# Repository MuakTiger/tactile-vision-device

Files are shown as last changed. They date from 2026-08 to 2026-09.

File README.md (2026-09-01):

# Tactile Vision Device
> Real-time visual-to-tactile substitution device for the visually impaired.  
> 카메라의 깊이 정보를 24개의 촉각 핀으로 변환해 공간을 손끝에 전달합니다.

---

## Hardware Preview

<a href="hardware/full/7_22 set_final.stl">
  
</a>

> Click the badge above, or click the STL file directly on GitHub to launch the interactive 3D viewer.

**[→ Open Full Assembly STL (interactive 3D viewer)](hardware/full/7_22%20set_final.stl)**

| Part | STL |
|---|---|
| Full Assembly (24-zone tactile display) | [7_22 set_final.stl](hardware/full/7_22%20set_final.stl) |
| Servo + Rack & Pinion unit | [SG90 and Rack and Pinion.stl](hardware/assembly/SG90%20and%20Rack%20and%20Pinion.stl) |
| Rack | [rack.stl](hardware/parts/rack.stl) |
| Pinion | [pinion.stl](hardware/parts/pinion.stl) |
| Servo bracket | [servo_bracket.stl](hardware/parts/servo_bracket.stl) |

---

## Project Structure

```
tactile-vision-device/
├── software/
│   ├── main.py              # Jetson main pipeline
│   ├── requirements.txt
│   └── pico/
│       └── main.cpp         # Raspberry Pi Pico firmware
└── hardware/
    ├── parts/               # rack.stl / pinion.stl / servo_bracket.stl
    ├── assembly/            # SG90 + rack & pinion unit
    └── full/                # complete 24-zone tactile display
```

---

## System Overview

```
Camera
  │
  ▼
Jetson Orin Developer Kit
  ├─ Depth Anything V2 (TensorRT)
  ├─ 6×4 grid depth mapping (24 zones)
  └─ UART  "GRID:v0,...,v23\n"
          │
          ▼
Raspberry Pi Pico
  ├─ I2C → PCA9685 #1 (0x40) → SG90 ×12  [rows 1–2]
  └─ I2C → PCA9685 #2 (0x41) → SG90 ×12  [rows 3–4]
                  │
                  ▼
        Rack & Pinion — Z-axis pin extrusion
```

## Grid Layout

```
[ 0][ 1][ 2][ 3][ 4][ 5]   row 1 ┐ PCA9685 0x40
[ 6][ 7][ 8][ 9][10][11]   row 2 ┘
[12][13][14][15][16][17]   row 3 ┐ PCA9685 0x41
[18][19][20][21][22][23]   row 4 ┘
```

Higher depth value = closer object = pin extends further.

---

## Hardware

| Component | Spec |
|---|---|
| Main board | NVIDIA Jetson Orin Developer Kit |
| MCU | Raspberry Pi Pico (RP2040) |
| PWM driver | PCA9685 × 2 (I2C: `0x40`, `0x41`) |
| Actuator | SG90 servo × 24 |
| Mechanism | Rack & pinion, Z-axis extrusion (3D printed) |
| Camera | USB webcam (MJPEG, 720p) |

---

## Getting Started

### Jetson

```bash
pip install -r software/requirements.txt
# Place TRT engine → checkpoints/depth_anything_v2_vits.engine

python software/main.py              # run
python software/main.py --debug      # with visualization
python software/main.py --no-hw      # software only
```

| Option | Default | Description |
|---|---|---|
| `--port` | `/dev/ttyACM0` | Pico serial port |
| `--baud` | `115200` | Baud rate |
| `--debug` | `False` | Show depth grid overlay |
| `--no-hw` | `False` | Run without hardware |

### Pico Firmware

1. Install [Arduino IDE](https://www.arduino.cc/en/software)
2. Add board URL in **Preferences**:
   ```
   https://github.com/earlephilhower/arduino-pico/releases/download/global/package_rp2040_index.json
   ```
3. Install **Raspberry Pi Pico/RP2040** via Board Manager
4. Install **Adafruit PWM Servo Driver Library**
5. Upload `software/pico/main.cpp`

**I2C wiring:** `GP4` → SDA, `GP5` → SCL

**Before first run** — lower `SAFE_MAX` in `pico/main.cpp` to avoid mechanical damage:
```cpp
static constexpr uint16_t SAFE_MAX = 350;  // increase gradually after testing
```

---

## References

- [Depth Anything V2](https://github.com/DepthAnything/Depth-Anything-V2)
- [Ultralytics YOLO](https://github.com/ultralytics/ultralytics)
- [Adafruit PWM Servo Driver](https://github.com/adafruit/Adafruit-PWM-Servo-Driver-Library)
- [arduino-pico](https://github.com/earlephilhower/arduino-pico)

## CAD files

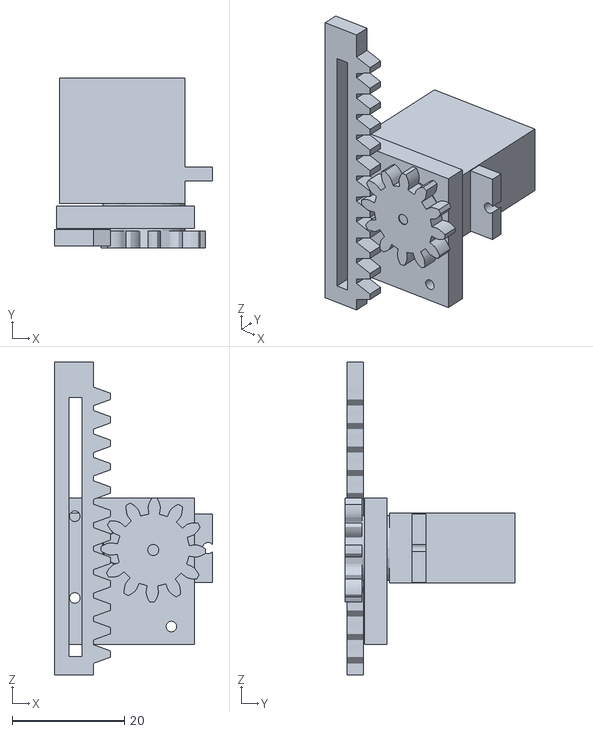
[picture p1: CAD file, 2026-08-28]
hardware/assembly/SG90 and Rack and Pinion.stl
28.2 x 30.4 x 55.9

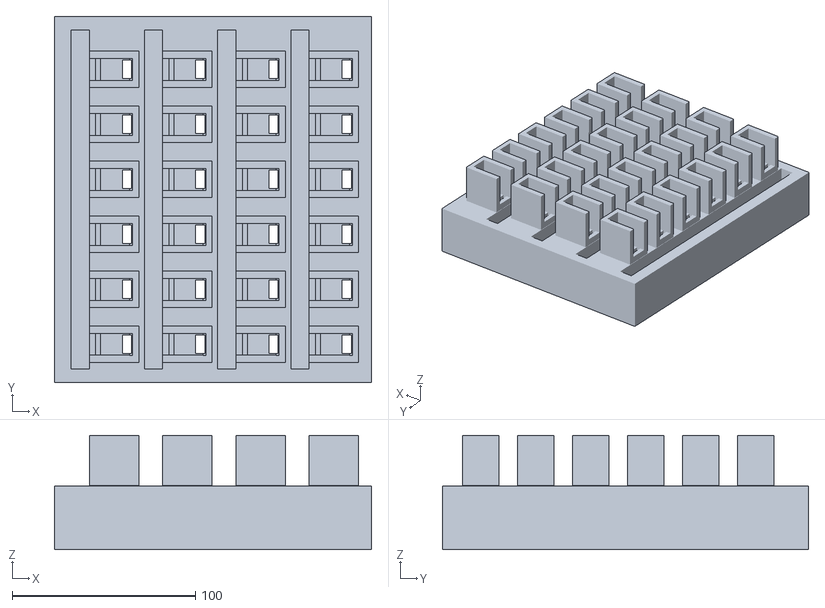
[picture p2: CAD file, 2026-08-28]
hardware/full/7_22 set_final.stl
173.0 x 200.0 x 62.3

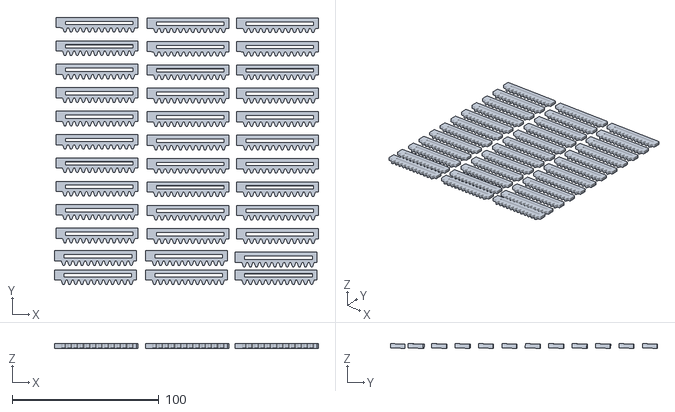
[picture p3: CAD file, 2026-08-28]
hardware/parts/rack.stl
179.9 x 182.1 x 3.17

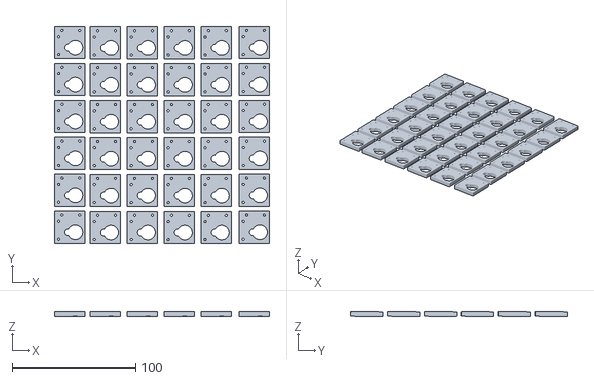
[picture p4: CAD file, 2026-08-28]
hardware/parts/servo_bracket.stl
174.7 x 176.5 x 4.46

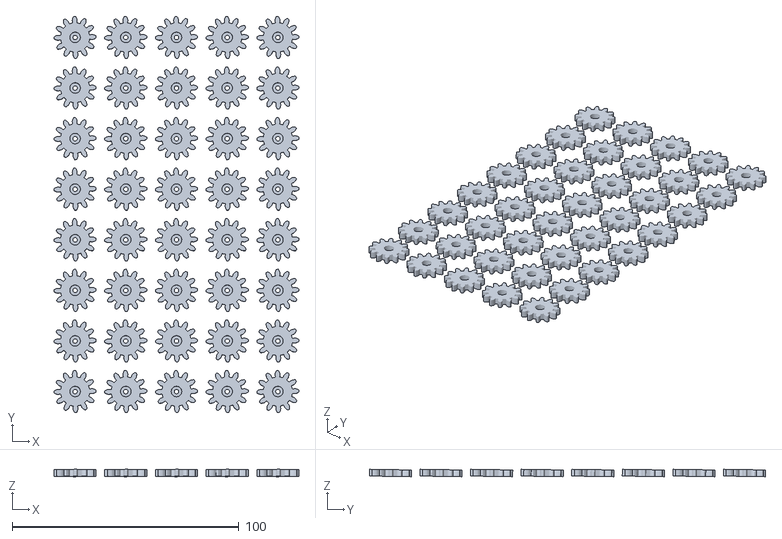
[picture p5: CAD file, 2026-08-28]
hardware/parts/pinion.stl
108.1 x 175.0 x 3.32

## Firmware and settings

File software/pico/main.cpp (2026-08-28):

/**
 * 시각-촉각 대체 보조장치 — Raspberry Pi Pico 펌웨어
 *
 * 구성:
 *   Jetson → USB UART → Pico → I2C → PCA9685 x2 → SG90 x24
 *   PCA9685 #1 (0x40): 채널 0~11 → 그리드 상단 12구역
 *   PCA9685 #2 (0x41): 채널 0~11 → 그리드 하단 12구역
 *
 * 수신 포맷: "GRID:v0,v1,...,v23\n"  (ASCII, 115200bps)
 *
 * 의존 라이브러리 (platformio.ini 또는 Arduino IDE):
 *   - Wire (내장)
 *   - adafruit/Adafruit PWM Servo Driver Library
 *
 * 하드웨어 연결:
 *   GP4 (SDA) → PCA9685 SDA
 *   GP5 (SCL) → PCA9685 SCL
 *   3V3 / GND → PCA9685 VCC / GND
 *   외부 5V   → PCA9685 V+ (서보 전원)
 */

#include <Arduino.h>
#include <Wire.h>
#include <Adafruit_PWMServoDriver.h>

// ──────────────────────────────────────────────
// 설정 상수
// ──────────────────────────────────────────────
static constexpr int    MOTOR_COUNT    = 24;
static constexpr int    BOARD_CH       = 12;   // 보드당 채널 수 (24 / 2)

// SG90 안전 PWM 범위 (50 Hz 기준, 4096 tick 단위)
// 랙앤피니언 실제 스트로크에 맞게 SAFE_MAX 조정 권장
// 처음 테스트 시: SAFE_MAX = 350 으로 낮게 시작
static constexpr uint16_t SAFE_MIN     = 250;  // ~0.5 ms → 핀 하강 (홈)
static constexpr uint16_t SAFE_MAX     = 490;  // ~2.3 ms → 핀 최대 상승

// 깊이값 하한 임계치 — 이 값 미만은 '물체 없음' → 홈 유지
static constexpr uint8_t  DEPTH_THR    = 20;

// 통신 Failsafe: 이 시간(ms) 동안 패킷 없으면 전체 홈 복귀
static constexpr unsigned long COMM_TIMEOUT = 2000;

// ──────────────────────────────────────────────
// PCA9685 객체
// ──────────────────────────────────────────────
Adafruit_PWMServoDriver pwm1 = Adafruit_PWMServoDriver(0x40); // 기본 보드
Adafruit_PWMServoDriver pwm2 = Adafruit_PWMServoDriver(0x41); // A0 납땜 보드

unsigned long lastReceiveTime = 0;

// ──────────────────────────────────────────────
// 전체 서보 홈 복귀
// ──────────────────────────────────────────────
void resetAllServos() {
  for (int i = 0; i < BOARD_CH; i++) {
    pwm1.setPWM(i, 0, SAFE_MIN);
    pwm2.setPWM(i, 0, SAFE_MIN);
  }
}

// ──────────────────────────────────────────────
// 깊이값(0~255) → PWM tick 변환
// Depth Anything V2: 값이 클수록 가까움 (disparity)
// → 가까울수록 막대가 더 올라옴 (SAFE_MAX 방향)
// ──────────────────────────────────────────────
uint16_t depthToPWM(uint8_t rawVal) {
  if (rawVal < DEPTH_THR) return SAFE_MIN;  // 물체 없음 → 홈
  return (uint16_t)map(rawVal, DEPTH_THR, 255, SAFE_MIN, SAFE_MAX);
}

// ──────────────────────────────────────────────
// 패킷 파싱: "GRID:v0,v1,...,v23"
// 반환값: 24개 파싱 성공 시 true
// ──────────────────────────────────────────────
bool parsePacket(const String& packet, uint8_t values[MOTOR_COUNT]) {
  if (!packet.startsWith("GRID:")) return false;

  String data = packet.substring(5);
  data.trim();

  char buf[128];
  data.toCharArray(buf, sizeof(buf));

  int    index = 0;
  char*  token = strtok(buf, ",");

  while (token != nullptr && index < MOTOR_COUNT) {
    int v       = atoi(token);
    values[index++] = (uint8_t)constrain(v, 0, 255);
    token = strtok(nullptr, ",");
  }

  return (index == MOTOR_COUNT);
}

// ──────────────────────────────────────────────
// 24개 서보 일괄 업데이트
// 가로 6 × 세로 4 그리드 (행 우선)
// index  0~11 → pwm1 (PCA9685 0x40) 채널 0~11  ← 상단 2행
// index 12~23 → pwm2 (PCA9685 0x41) 채널 0~11  ← 하단 2행
// ──────────────────────────────────────────────
void applyServos(uint8_t values[MOTOR_COUNT]) {
  for (int i = 0; i < BOARD_CH; i++) {
    pwm1.setPWM(i, 0, depthToPWM(values[i]));
    pwm2.setPWM(i, 0, depthToPWM(values[i + BOARD_CH]));
  }
}

// ──────────────────────────────────────────────
// 초기화
// ──────────────────────────────────────────────
void setup() {
  Wire.begin();               // GP4=SDA, GP5=SCL (arduino-pico 기본값)
  Serial.begin(115200);
  Serial.setTimeout(100);

  pwm1.begin();
  pwm1.setPWMFreq(50);        // SG90 표준 주파수 50 Hz

  pwm2.begin();
  pwm2.setPWMFreq(50);

  resetAllServos();           // 부팅 시 전체 홈 복귀
  delay(500);

  Serial.println("PICO_READY");
  lastReceiveTime = millis();
}

// ──────────────────────────────────────────────
// 메인 루프
// ──────────────────────────────────────────────
void loop() {
  // ── A. 패킷 수신 및 처리 ──
  if (Serial.available() > 0) {
    String packet = Serial.readStringUntil('\n');
    packet.trim();

    uint8_t values[MOTOR_COUNT];
    if (parsePacket(packet, values)) {
      applyServos(values);
      lastReceiveTime = millis();
    }
    // 파싱 실패 시 이전 포지션 유지 (갑작스러운 움직임 방지)
  }

  // ── B. Failsafe: 통신 단절 시 홈 복귀 ──
  if (millis() - lastReceiveTime > COMM_TIMEOUT) {
    resetAllServos();
    lastReceiveTime = millis();  // 반복 호출 방지
  }
}

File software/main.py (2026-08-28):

"""
시각장애인을 위한 실시간 시각-촉각 대체 보조장치
Jetson Orin Developer Kit 구동용 메인 파이프라인

파이프라인:
  웹캠 → Depth Anything V2 (TensorRT) → 4×6 그리드(가로6×세로4) → 시리얼 → Pico → PCA9685×2 → SG90×24

실행 예시:
  python main.py --debug                         # 시각화 창 포함 실행
  python main.py --no-hw                         # 하드웨어 없이 시각화만
  python main.py --port /dev/ttyACM1 --debug     # 시리얼 포트 지정
"""

import argparse
import logging
import time

import cv2
import numpy as np
import serial
import torch
import tensorrt as trt

# ──────────────────────────────────────────────────────────────────
# 로깅 설정
# ──────────────────────────────────────────────────────────────────
logging.basicConfig(
    level=logging.INFO,
    format="%(asctime)s [%(levelname)s] %(message)s",
)
logger = logging.getLogger(__name__)


# ──────────────────────────────────────────────────────────────────
# Depth Anything V2 – TensorRT 추론 클래스
# ──────────────────────────────────────────────────────────────────
class DepthEstimatorTRT:
    """
    Depth Anything V2 ViT-S TensorRT 엔진 래퍼.
    입력: BGR 518×518 ndarray
    출력: uint8 깊이맵 (0~255, 값이 클수록 가까움 – disparity 기반)
    """

    # ImageNet 정규화 상수
    MEAN = np.array([0.485, 0.456, 0.406], dtype=np.float32).reshape(3, 1, 1)
    STD  = np.array([0.229, 0.224, 0.225], dtype=np.float32).reshape(3, 1, 1)

    def __init__(self, engine_path: str, input_shape: tuple = (518, 518)):
        self.input_shape = input_shape

        trt_logger = trt.Logger(trt.Logger.WARNING)
        trt.init_libnvinfer_plugins(trt_logger, "")

        with open(engine_path, "rb") as f, trt.Runtime(trt_logger) as runtime:
            self.engine = runtime.deserialize_cuda_engine(f.read())

        self.context = self.engine.create_execution_context()
        self.stream  = torch.cuda.Stream()

        # 추론 버퍼 사전 할당 (매 프레임 메모리 재할당 방지)
        self.d_input  = torch.empty((1, 3, *input_shape), dtype=torch.float32, device="cuda")
        self.d_output = torch.empty((1, *input_shape),    dtype=torch.float32, device="cuda")
        self.context.set_tensor_address("input",  int(self.d_input.data_ptr()))
        self.context.set_tensor_address("output", int(self.d_output.data_ptr()))

        logger.info("DepthEstimator TRT 로드 완료: %s", engine_path)

    def infer(self, frame_518: np.ndarray) -> np.ndarray:
        """BGR 518×518 → 정규화 깊이맵 (uint8)"""
        # BGR → RGB → float32 정규화
        img = cv2.cvtColor(frame_518, cv2.COLOR_BGR2RGB).astype(np.float32) / 255.0
        img = (img.transpose(2, 0, 1) - self.MEAN) / self.STD  # (3, H, W)

        with torch.cuda.stream(self.stream):
            self.d_input.copy_(
                torch.from_numpy(np.ascontiguousarray(img[None])), non_blocking=True
            )
            self.context.execute_async_v3(stream_handle=self.stream.cuda_stream)
            self.stream.synchronize()

        depth_raw  = self.d_output.cpu().numpy()[0]
        depth_norm = cv2.normalize(depth_raw, None, 0, 255, cv2.NORM_MINMAX, dtype=cv2.CV_8U)
        return depth_norm


# ──────────────────────────────────────────────────────────────────
# 시리얼 통신 클래스 (젯슨 → 피코)
# ──────────────────────────────────────────────────────────────────
class HardwareCommunicator:
    """
    Raspberry Pi Pico와의 UART 시리얼 통신.
    전송 포맷: "GRID:v0,v1,...,v23\\n"  (ASCII 문자열)
    """

    def __init__(self, port: str, baudrate: int = 115200):
        self.conn = None
        try:
            self.conn = serial.Serial(port, baudrate, timeout=1.0)
            time.sleep(2.0)  # 피코 부팅 대기

            # 피코 준비 신호 수신 확인
            resp = self.conn.readline().decode("utf-8", errors="ignore").strip()
            if resp == "PICO_READY":
                logger.info("피코 연결 확인 (%s)", port)
            else:
                logger.warning("피코 응답 불명확: '%s' — 계속 진행합니다.", resp)

        except serial.SerialException as e:
            logger.warning("시리얼 연결 실패 (%s): %s → 오프라인 모드", port, e)

    @property
    def connected(self) -> bool:
        return self.conn is not None and self.conn.is_open

    def transmit(self, grid_values: list) -> bool:
        """24개 그리드 값을 피코로 전송. 성공 시 True 반환."""
        if not self.connected:
            return False
        packet = "GRID:" + ",".join(map(str, grid_values)) + "\n"
        try:
            self.conn.write(packet.encode("utf-8"))
            return True
        except serial.SerialException as e:
            logger.error("전송 실패: %s", e)
            return False

    def close(self):
        if self.connected:
            self.conn.close()
            logger.info("시리얼 포트 닫힘")


# ──────────────────────────────────────────────────────────────────
# 6×4 그리드 깊이 산출
# ──────────────────────────────────────────────────────────────────
def compute_grid(depth_norm: np.ndarray,
                 grid_h: int = 4,
                 grid_w: int = 6) -> list:
    """
    깊이맵 → 24개 구역 평균값 리스트 (행 우선, 좌→우, 위→아래)
    가로 6구역 × 세로 4구역 (사람 눈/모니터 비율 기준)

    인덱스 배치:
      [ 0  1  2  3  4  5]  ← 1행
      [ 6  7  8  9 10 11]  ← 2행  → PCA9685 0x40 (채널 0~11)
      [12 13 14 15 16 17]  ← 3행
      [18 19 20 21 22 23]  ← 4행  → PCA9685 0x41 (채널 0~11)
    """
    result = []
    for row_strip in np.array_split(depth_norm, grid_h, axis=0):
        for cell in np.array_split(row_strip, grid_w, axis=1):
            result.append(int(np.mean(cell)))
    return result  # len == 24


# ──────────────────────────────────────────────────────────────────
# 디버그 시각화
# ──────────────────────────────────────────────────────────────────
def draw_debug(depth_norm: np.ndarray,
               grid_values: list,
               fps: float,
               grid_h: int = 4,
               grid_w: int = 6) -> np.ndarray:
    """깊이맵에 그리드 오버레이 + FPS 표시"""
    vis = cv2.applyColorMap(depth_norm, cv2.COLORMAP_INFERNO)
    h, w = vis.shape[:2]
    rh, rw = h // grid_h, w // grid_w

    for r in range(grid_h):
        for c in range(grid_w):
            idx  = r * grid_w + c
            x1, y1 = c * rw, r * rh
            # 두 보드 경계(인덱스 12, 3행 시작) 강조
            border = (0, 255, 255) if idx == 12 else (180, 180, 180)
            cv2.rectangle(vis, (x1, y1), (x1 + rw, y1 + rh), border, 1)
            cv2.putText(
                vis, str(grid_values[idx]),
                (x1 + 4, y1 + 18),
                cv2.FONT_HERSHEY_SIMPLEX, 0.42,
                (255, 255, 255), 1, cv2.LINE_AA,
            )

    cv2.putText(
        vis, f"FPS: {fps:.1f}",
        (6, h - 8), cv2.FONT_HERSHEY_SIMPLEX,
        0.65, (0, 255, 0), 2, cv2.LINE_AA,
    )
    return vis
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

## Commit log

2026-08-28 feat: 시각-촉각 대체 보조장치 초기 구현
    - main.py: Depth Anything V2 TRT 추론 + 6×4 그리드 + 시리얼 전송
    - pico/main.cpp: PCA9685×2 I2C 제어, strtok 파싱, Failsafe
    - requirements.txt, README.md, .gitignore 추가
    [main.cpp, main.py]
2026-08-28 Update actuator description in README.md
2026-08-28 fix: 그리드 방향 수정 및 하드웨어 표기 정확화
    - 그리드 방향: 세로6×가로4 → 가로6×세로4 (GRID_H=4, GRID_W=6)
    - 메인보드: Jetson Orin Developer Kit으로 수정
    - 피코 설명: Raspberry Pi Pico (RP2040) 명확화
    - 그리드 인덱스 배치 주석 업데이트 (main.py, pico/main.cpp, README)
    [main.cpp, main.py]
2026-08-28 refactor: software/hardware 디렉토리 분리 및 STL 파일 추가
    [7_22 set_final.stl, SG90 and Rack and Pinion.stl, pinion.stl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]
2026-08-28 docs: README 간결화 및 구조 재배치
2026-09-01 docs: add Hardware Preview section with STL 3D viewer links
2026-10-21 feat: 2·3층 하우징(3단 케이크 구조) STL 및 생성 스크립트 추가
    - hardware/stack/: 2층(전자부), 3층(젯슨·보조배터리·C920), 좌우 틈 막대
    - print_plate_nested.stl: 2층을 90도 돌려 3층 안에 넣은 H2D 한 판 출력 배치
    - stack_tiers.py: 파라미터 기반 생성 스크립트 (trimesh + manifold3d)
    - README: 하우징 구조, 출력 방법(normal(auto) 서포트) 정리
